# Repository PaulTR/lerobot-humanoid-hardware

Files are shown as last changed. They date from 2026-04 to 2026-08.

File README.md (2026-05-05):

# lerobot-humanoid-hardware

Hardware repository for **LeRobot Humanoid**.

This repo stores the practical build assets needed to reproduce the robot hardware:
- mechanical assembly documentation
- manufacturing files and notes
- electronics wiring and connector mapping
- bill of materials (BOM)
- motor pre-assembly commissioning tooling

## Current scope

- `IN`: biped platform hardware
- `OUT` (for now): upper-body hardware

The Onshape document currently contains an upper-body model as well, but this repository iteration tracks only the biped platform assets.

## CAD source of truth

Primary CAD source (Onshape):
- **Public Onshape CAD (open this first):** https://cad.onshape.com/documents/fb645318a27646d1d8840be6/w/d1cae8805fb652b4d1614997/e/804a1da43f242001a05129b4

Referenced IDs:
- Document ID: `fb645318a27646d1d8840be6`
- Workspace ID: `d1cae8805fb652b4d1614997`
- Element ID: `804a1da43f242001a05129b4`

## Repository layout

- `docs/`: architecture, guides, and procedures
- `hardware/cad/`: Onshape source reference and exported STL geometry
- `hardware/bom/`: BOM in machine-readable and human-readable formats
- `hardware/config/`: motor commissioning utilities
- `hardware/electronics/`: wiring and connector mapping

## CAD organization

`hardware/cad/stl/` is split by side and subassembly:
- `biped_platform/left_leg/{hipx,hipz,thigh,knee_mechanism,shin,ankle_mechanism,ankle,foot}`
- `biped_platform/right_leg/{hipx,hipz,thigh,knee_mechanism,shin,ankle_mechanism,ankle,foot}`
- `biped_platform/torso`

This mirrors the assembly view and makes part export placement explicit.

## Runtime integration

Runtime repository (robot model and control runtime) lives in:
- https://github.com/Virgileboat/lerobot-humanoid-runtime

Motor commissioning script in this repo is self-contained and does **not** depend on `robstride_toolkit`.

Main scripts:
- `hardware/config/commission_motor.py`

## Start Sequence (Human + Agent)

Use this preferred order to start a new build:

1. Order all buy parts from `hardware/bom/bom_buy.csv` first.
2. Print all required STL parts from `docs/manufacturing/printing_guide.md`.
3. Commission and check every motor before assembly:
   - `docs/electronics/motor_commissioning.md`
   - `python hardware/config/commission_motor.py wizard --channel can0`
4. Assemble mechanical subassemblies using `docs/assembly/assembly_guide.md`.
5. Run wiring and first power-on checks:
   - `docs/electronics/check_wiring.md`
   - `docs/electronics/first_power_on.md`

Important rule:
- Do not start mechanical assembly before motor protocol/ID commissioning and motion check are completed.

## Support

If you are blocked on build, printing, electronics, or assembly details:
- contact: `virgilebatto@gmail.com`

## Working model

1. Modify design in Onshape.
2. Export manufacturing/build assets to this repository.
3. Update BOM/config/docs in the same commit.
4. Keep all biped-platform changes traceable to a CAD revision.

## BOM Split (Robot Qty)

### STL BOM

| Subassembly | STL files to print |
|---|---:|
| torso | 7 |
| hipx | 2 |
| hipz | 4 |
| thigh | 6 |
| knee_mechanism | 6 |
| shin | 12 |
| ankle_mechanism | 16 |
| ankle | 10 |
| foot | 12 |
| **Total** | **75** |

Detailed STL names and quantities:
- [Printing guide](docs/manufacturing/printing_guide.md)
- [BOM total (clickable STL rows)](hardware/bom/bom.md)
- [BOM CSV (`category=stl_print`)](hardware/bom/bom.csv)

### Bearing/Revolute BOM

| Name | Specification | Qty (robot) |
|---|---|---:|
| Bearing | 35x72x17 | 4 |
| Bearing | 15x21x4 | 14 |
| Bearing | 5x16x5 | 8 |
| Spherical joint 27628-01-05 | Norelem | 8 |

### Axis BOM

| Name | Specification | Qty (robot) | Usage |
|---|---|---:|---|
| Shoulder screw 07534-05X40 | ISO7379, D1=5, L1=40, B=8, M4, SW=2.5, steel 12.9 | 4 | thigh (2) + ankle (2) |
| Shoulder screw 07534-05X20 | ISO7379, D1=5, L1=20, B=8, M4, steel 12.9 | 8 | ankle_mechanism (8) |

### Screw BOM

| Name | Specification | Qty (robot) |
|---|---|---:|
| M2 screw | M2 x 5 cyl head | 4 |
| M2.5 screw | M2.5 x 20 cyl head | 9 |
| M2.5 screw | M2.5 x 6 cyl head | 6 |
| M2.5 screw | M2.5 x 8 cyl head | 24 |
| M3 screw | M3 x 8 cyl head | 18 |
| M3 screw | M3 x 10 cyl head | 48 |
| M3 screw | M3 x 12.5 cyl head | 6 |
| M3 screw | M3 x 17.5 cyl head | 8 |
| M4 screw | M4 x 8 cyl head | 36 |
| M4 screw | M4 x 10 cyl head | 42 |
| M4 screw | M4 x 16 cyl head | 16 |
| M4 screw | M4 x 18 cyl head | 32 |
| M4 screw | M4 x 20 cyl head | 32 |
| M4 screw | M4 x 23.5 cyl head | 8 |
| M4 screw | M4 x 40 cyl head | 12 |
| M4 screw | M4 x 45 cyl head | 18 |
| M5 screw | M5 x 10 cyl head | 5 |
| M5 screw | M5 x 15 cyl head | 8 |

## Cost estimate (Biped Platform, April 30 2026)

Scope of this estimate:
- all buy items in `hardware/bom/bom_buy.csv`
- plus PLA+ filament for printing (`~3.5 kg` used for estimate, target range `3-4 kg`)

Assumptions:
- currency: `USD`
- prices are indicative and vendor-dependent
- excludes shipping, import duties, and local taxes
- fastener prices use bulk-piece estimates
- EUR-priced references converted with `1 EUR = 1.1691 USD` (snapshot on `May 5, 2026`)
- `hipx` M3 screw line is optional and can be removed without issue

| Subassembly | Category | Name | Specification | Qty (robot) | Unit est. (USD) | Subtotal est. (USD) |
|---|---|---|---|---:|---:|---:|
| torso | electronics_controller | Raspberry Pi 5 | single-board computer | 1 | 130.00 | 130.00 |
| torso | electronics_imu | IMU | BNO055 or BNO085 | 1 | 64.00 | 64.00 |
| torso | electronics_canfd_adapter | SAVVYCANFD 2CH CANFD adapter | USB, dual CAN FD, 12 Mbps max | 1 | 59.00 | 59.00 |
| torso | cable_power | Power cable red | diameter >= 2.5 mm, 5 m | 1 | 15.00 | 15.00 |
| torso | cable_power | Power cable black | diameter >= 2.5 mm, 5 m | 1 | 15.00 | 15.00 |
| torso | cable_communication | Communication cable color 1 | 5 m | 1 | 8.00 | 8.00 |
| torso | cable_communication | Communication cable color 2 | 5 m | 1 | 8.00 | 8.00 |
| torso | motor | RobStride O0 | actuator | 2 | 125.00 | 250.00 |
| torso | fastener_screw | M2 screw | M2 x 5 cyl head | 4 | 0.10 | 0.40 |
| torso | fastener_screw | M2.5 screw | M2.5 x 20 cyl head | 9 | 0.12 | 1.08 |
| torso | fastener_screw | M3 screw | M3 x 8 cyl head | 12 | 0.10 | 1.20 |
| torso | fastener_screw | M4 screw | M4 x 20 cyl head | 16 | 0.14 | 2.24 |
| torso | fastener_screw | M5 screw | M5 x 10 cyl head | 5 | 0.20 | 1.00 |
| hipx | fastener_screw | M3 screw | M3 x 8 cyl head | 6 | 0.10 | 0.60 |
| hipx | fastener_screw | M4 screw | M4 x 40 cyl head | 12 | 0.17 | 2.04 |
| hipx | fastener_screw | M4 screw | M4 x 45 cyl head | 18 | 0.20 | 3.60 |
| hipx | fastener_screw | M4 screw | M4 x 8 cyl head | 16 | 0.10 | 1.60 |
| hipz | motor | RobStride O2 | actuator | 2 | 145.00 | 290.00 |
| hipz | bearing | Bearing | 35x72x17 | 4 | 8.27 | 33.08 |
| hipz | fastener_screw | M4 screw | M4 x 10 cyl head | 16 | 0.11 | 1.76 |
| hipz | fastener_screw | M4 screw | M4 x 20 cyl head | 16 | 0.14 | 2.24 |
| thigh | motor | RobStride O3 | actuator | 4 | 225.00 | 900.00 |
| thigh | bearing | Bearing | 15x21x4 | 2 | 3.00 | 6.00 |
| thigh | bearing | Bearing | 5x16x5 | 4 | 1.87 | 7.48 |
| thigh | fastener_screw | M2.5 screw | M2.5 x 6 cyl head | 6 | 0.09 | 0.54 |
| thigh | fastener_screw | M4 screw | M4 x 10 cyl head | 8 | 0.11 | 0.88 |
| thigh | fastener_screw | M4 screw | M4 x 23.5 cyl head | 8 | 0.16 | 1.28 |
| thigh | fastener_screw | M4 screw | M4 x 8 cyl head | 20 | 0.10 | 2.00 |
| thigh | fastener_axis | Shoulder screw 07534-05X40 | ISO7379, D1=5, L1=40, B=8, M4, SW=2.5, steel 12.9 | 2 | 8.18 | 16.36 |
| knee_mechanism | bearing | Bearing | 15x21x4 | 4 | 3.00 | 12.00 |
| knee_mechanism | fastener_screw | M3 screw | M3 x 12.5 cyl head | 6 | 0.11 | 0.66 |
| knee_mechanism | fastener_screw | M4 screw | M4 x 16 cyl head | 16 | 0.12 | 1.92 |
| shin | motor | RobStride O5 | actuator | 4 | 110.00 | 440.00 |
| shin | bearing | Bearing | 15x21x4 | 8 | 3.00 | 24.00 |
| shin | fastener_screw | M2.5 screw | M2.5 x 8 cyl head | 6 | 0.10 | 0.60 |
| shin | fastener_screw | M3 screw | M3 x 17.5 cyl head | 8 | 0.12 | 0.96 |
| shin | fastener_screw | M3 screw | M3 x 10 cyl head | 48 | 0.10 | 4.80 |
| shin | fastener_screw | M4 screw | M4 x 18 cyl head | 32 | 0.14 | 4.48 |
| shin | fastener_screw | M4 screw | M4 x 10 cyl head | 18 | 0.11 | 1.98 |
| shin | fastener_nut | Nut M4 | M4 nut | 6 | 0.08 | 0.48 |
| shin | fastener_insert | Heat-set insert M3 | brass threaded insert M3 | 8 | 0.10 | 0.80 |
| ankle_mechanism | fastener_screw | M5 screw | M5 x 15 cyl head | 8 | 0.24 | 1.92 |
| ankle_mechanism | joint_spherical | Spherical joint 27628-01-05 | Norelem | 8 | 20.93 | 167.44 |
| ankle_mechanism | fastener_axis | Shoulder screw 07534-05X20 | ISO7379, D1=5, L1=20, B=8, M4, steel 12.9 | 8 | 6.35 | 50.80 |
| ankle | fastener_screw | M2.5 screw | M2.5 x 8 cyl head | 12 | 0.10 | 1.20 |
| ankle | fastener_axis | Shoulder screw 07534-05X40 | ISO7379, D1=5, L1=40, B=8, M4, SW=2.5, steel 12.9 | 2 | 8.18 | 16.36 |
| foot | bearing | Bearing | 5x16x5 | 4 | 1.87 | 7.48 |
| foot | fastener_screw | M2.5 screw | M2.5 x 8 cyl head | 6 | 0.10 | 0.60 |
| foot | fastener_nut | Nut M4 | M4 nut | 6 | 0.08 | 0.48 |
| assembly_pins | fastener_pin | Pin d3mm | d3 pin (goupille) | 8 | 0.45 | 3.60 |
| assembly_pins | fastener_pin | Pin d4mm | d4 pin (goupille) | 18 | 0.55 | 9.90 |
| tools | tool | Allen key | 2.5 mm | 1 | 3.00 | 3.00 |
| manufacturing | consumable_filament | PLA+ filament | ~3.5 kg total (target range 3-4 kg) | 1 | 56.00 | 56.00 |

| Cost block | Estimate (USD) |
|---|---:|
| ankle subtotal | 17.56 |
| ankle_mechanism subtotal | 220.16 |
| assembly_pins subtotal | 13.50 |
| foot subtotal | 8.56 |
| hipx subtotal | 7.84 |
| hipz subtotal | 327.08 |
| knee_mechanism subtotal | 14.58 |
| shin subtotal | 478.10 |
| thigh subtotal | 934.54 |
| tools subtotal | 3.00 |
| torso subtotal | 554.92 |
| BOM-to-buy subtotal (without filament) | 2579.84 |
| PLA+ subtotal (~3.5 kg) | 56.00 |
| **Estimated total** | **2635.84** |

Price anchors used for key components:
- RobStride official site (motors): https://www.robstride.com/
- RobStride official product information: https://github.com/RobStride/Product_Information
- Raspberry Pi 5 (8GB): https://www.sparkfun.com/products/23551
- IMU BNO085: https://www.ardusimple.com/product/adafruit-9-dof-orientation-imu-fusion-breakout-bno085/
- SAVVYCANFD adapter: https://www.pibiger-tech.com/product/savvycan-fd-c/
- Bearing 5x16x5 reference price (123roulement): https://www.123roulement.com/roulement-palier/roulement-bille/simple-rangee/625-zz
- Bearing 35x72x17 reference price (123roulement): https://www.123roulement.com/roulement-palier/roulement-bille/simple-rangee/6207
- Norelem shoulder screw series 07534 (axis refs 07534-05X20 / 07534-05X40): https://www.norelem.fr/fr/Aper%C3%A7u%2Bdu%2Bproduit/Syst%C3%A8me-flexible-de-pi%C3%A8ces-standardis%C3%A9es/07000/%C3%89crous-vis-rondelles-%C3%A9l%C3%A9ments-de-fi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
- Norelem rod end series 27628 (spherical joint ref 27628-01-05): https://www.norelem.fr/en/Product-overview/Systems-and-components-for-machine-and-plant-construction/27000/Rod-ends/Rod-ends-with-plain-bearing-internal-thread-DIN-I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
- PLA+ reference price: https://us.elegoo.com/products/elegoo-rapid-pla-plus-filament-1-75mm-colored-1kg

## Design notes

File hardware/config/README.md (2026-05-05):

# Config

This folder is for pre-assembly motor commissioning only.

Tool:
- `commission_motor.py`

Typical use:

```bash
python hardware/config/commission_motor.py scan --channel can0
python hardware/config/commission_motor.py wizard --channel can0
python hardware/config/commission_motor.py wizard --channel can0 --motor-model o3 --new-id 4 --yes
```

Scope boundary:
- robot model and runtime control are maintained in https://github.com/Virgileboat/lerobot-humanoid-runtime

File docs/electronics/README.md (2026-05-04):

# Electronics

Electronics documentation for the biped platform.

Core artifacts:
- full wiring diagram image (`hardware/electronics/wiring_diagram.png`)
- connector and pin mapping (`hardware/electronics/connectors.md`)
- connector photo catalog (`hardware/electronics/connectors_photos/`)
- leg sub-cable diagrams with embedded images (`hardware/electronics/cabling/README.md`)
- power distribution notes
- controller and actuator bus topology

Leg sub-cable set (same cabling for left and right leg):
- legend, shin, thigh, and hip pass-through diagrams are embedded in `hardware/electronics/cabling/README.md`.

Motor pre-assembly commissioning:
- detailed workflow: `docs/electronics/motor_commissioning.md`
- tool: `hardware/config/commission_motor.py`
- recommended entrypoint: `wizard` command
- covers protocol detection, MIT switch, model-based ID assignment, and motion check

Implementation note:
- this script embeds only the CAN functions it uses; it does not import `robstride_toolkit`.

Bring-up runbooks:
- `docs/electronics/check_wiring.md`
- `docs/electronics/first_power_on.md`

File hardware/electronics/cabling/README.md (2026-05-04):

# Leg Cabling Diagrams

This folder contains the leg sub-cable diagrams used on the robot.

The same cabling architecture is used for both left and right legs.
The split by `shin` / `thigh` / `hip` is intentional to simplify debugging and repair.

## Legend

`red = power`, `green = CAN`, `blue = CAN + power`

Cable legend

## Shin sub-cable

Shin sub-cable

## Thigh sub-cable

Thigh sub-cable

## Hip pass-through sub-cable

Hip pass-through sub-cable

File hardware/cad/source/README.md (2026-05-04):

# CAD Source

Canonical CAD is maintained in Onshape:
- https://cad.onshape.com/documents/fb645318a27646d1d8840be6/w/d1cae8805fb652b4d1614997/e/804a1da43f242001a05129b4

Reference IDs:
- document: `fb645318a27646d1d8840be6`
- workspace: `d1cae8805fb652b4d1614997`
- default element: `804a1da43f242001a05129b4`

Current repo scope:
- biped platform only

CAD organization for this repo:
- `biped_platform/left_leg/`
- `biped_platform/right_leg/`
- `biped_platform/torso/`

Export policy:
1. Keep Onshape as source of truth.
2. Export `STL` for manufacturing where needed.
3. Include date/revision in exported filenames.
4. Update BOM and docs in the same commit.

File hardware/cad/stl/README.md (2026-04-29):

# STL Exports

Store manufacturing meshes (`.stl`) here.

Split exports by assembly hierarchy:
- `biped_platform/left_leg/<group>/...`
- `biped_platform/right_leg/<group>/...`
- `biped_platform/torso/...`

Current leg groups:
- `ankle`
- `ankle_mechanism`
- `foot`
- `hipx`
- `hipz`
- `knee_mechanism`
- `shin`
- `thigh`

Filename convention:
- ASCII lowercase snake_case.
- No spaces.
- No parentheses, so no `(1)`, `(2)`, etc.
- Repeated physical instances keep explicit numeric indices in the name (example: `...14...`, `...24...`, `...34...`, `...44...`).

Example:
`right_leg/shin/tibias2_tibias22.stl`

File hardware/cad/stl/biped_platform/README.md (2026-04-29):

# Biped Platform STL

Store STL exports split by side and mechanical group.

Main structure:
- `left_leg/<group>/...`
- `right_leg/<group>/...`
- `torso/...`

Per-leg groups currently used:
- `ankle`
- `ankle_mechanism`
- `foot`
- `hipx`
- `hipz`
- `knee_mechanism`
- `shin`
- `thigh`

Filename rule:
- Use lowercase snake_case.
- Do not use parentheses in filenames.
- Keep explicit instance indices when the same part appears multiple times.

Example path:
`right_leg/ankle_mechanism/bearing_spacer14_5_7_3.stl`

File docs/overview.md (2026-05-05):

# Overview

This repository is the build reference for **LeRobot Humanoid hardware**.

## Scope boundary

Current tracked hardware scope:
- biped platform (legs + base-related hardware)

Not yet tracked in this repo iteration:
- upper-body hardware present in the current Onshape document

## Source systems

- CAD source of truth: Onshape document (`fb645318a27646d1d8840be6`)
- Build source of truth: this repository
- Runtime control/model source: https://github.com/Virgileboat/lerobot-humanoid-runtime

## CAD split

CAD source is maintained in Onshape.  
This repository stores STL exports under:
- `hardware/cad/stl/biped_platform/left_leg/*`
- `hardware/cad/stl/biped_platform/right_leg/*`
- `hardware/cad/stl/biped_platform/torso/*`

## Traceability rules

For every hardware change:
1. Link it to a CAD revision/context in commit message or PR notes.
2. Update BOM (`hardware/bom/bom.csv`) if parts change.
3. If geometry/kinematics change, update runtime model/control artifacts in https://github.com/Virgileboat/lerobot-humanoid-runtime.
4. Update assembly/manufacturing docs if process changes.

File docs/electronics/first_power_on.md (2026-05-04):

# First Power-On Procedure

## Phase 1: logic power only

1. Power controller logic rails only.
2. Set bench supply current limit to `2 A` for this first test phase (no motion capability expected).
3. Confirm expected idle current is around `1 A` maximum.
4. If current rises above `2 A`, stop immediately and re-check wiring before continuing.
5. Confirm communication with all controller nodes.
6. Verify watchdog/heartbeat behavior.

## Phase 2: actuator power with safety limits

1. Set low current/torque limits.
2. Enable one actuator at a time.
3. Verify sign/direction and encoder consistency.
4. Disable immediately if unexpected motion occurs.

## Phase 3: low-amplitude validation

1. Execute tiny motion commands around neutral position.
2. Confirm software limits are enforced.
3. Log observed offsets and runtime notes for later integration in `lerobot_humanoid_runtime`.

Stop criteria:
- unexpected heating, smell, noise, or oscillation
- communication instability under load
- any limit/safety mismatch

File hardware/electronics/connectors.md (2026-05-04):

# Connectors

## Visual connector catalog (used on this robot)

### Inter-cable connector (male)

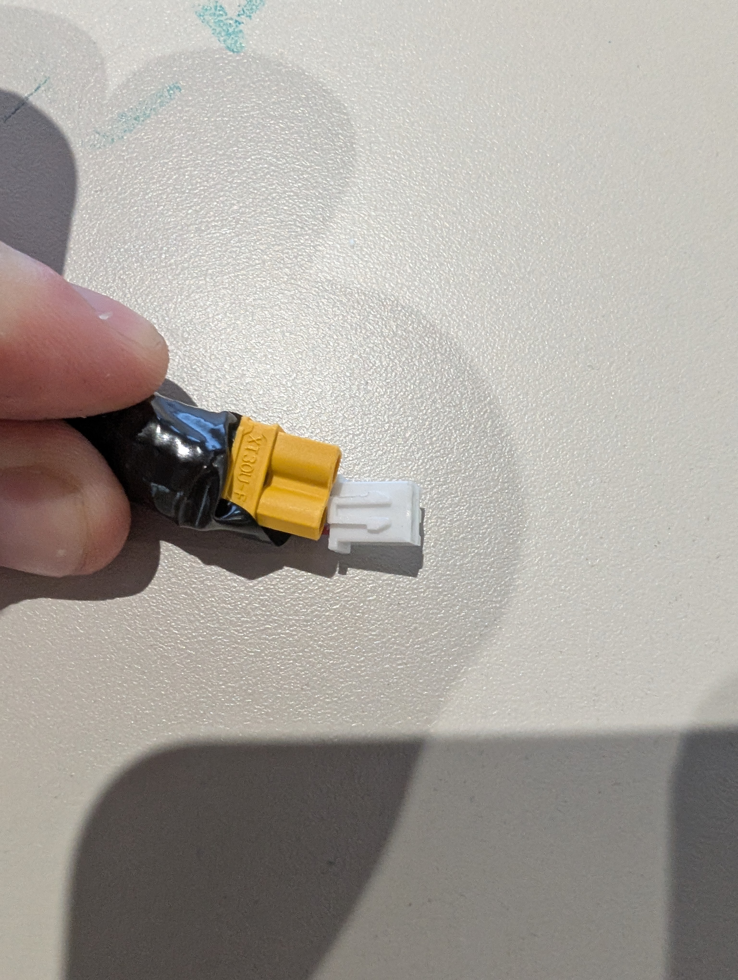
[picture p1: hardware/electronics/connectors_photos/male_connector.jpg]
Inter-cable male connector


### Inter-cable connector (female)

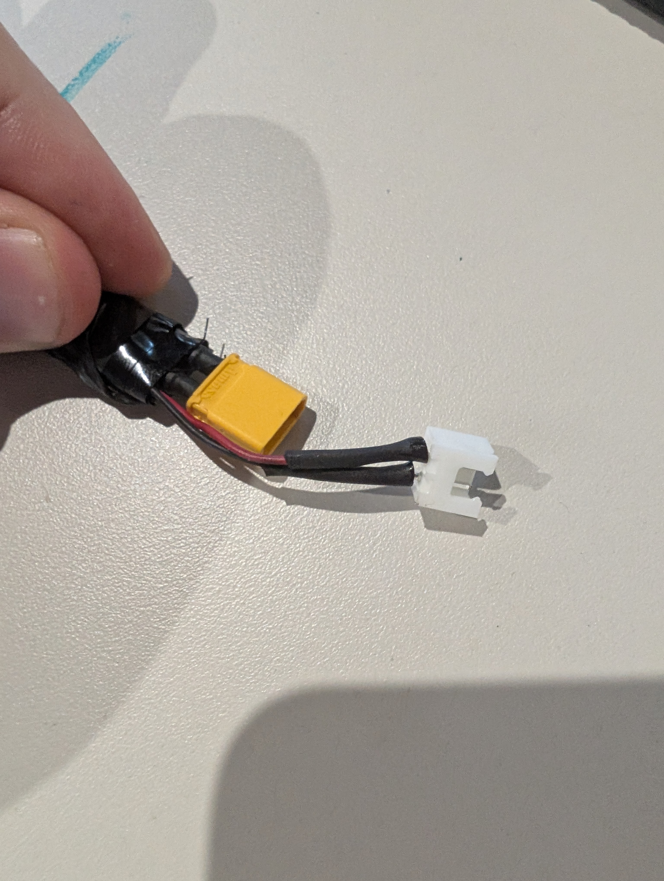
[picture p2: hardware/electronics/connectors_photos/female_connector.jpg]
Inter-cable female connector


### RobStride O3-side connector

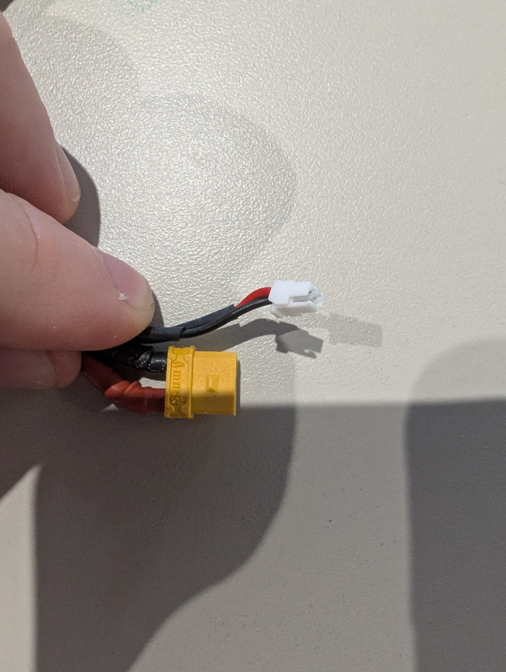
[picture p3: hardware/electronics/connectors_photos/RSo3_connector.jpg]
RobStride O3 connector


### RobStride connector (other RobStride models used here)

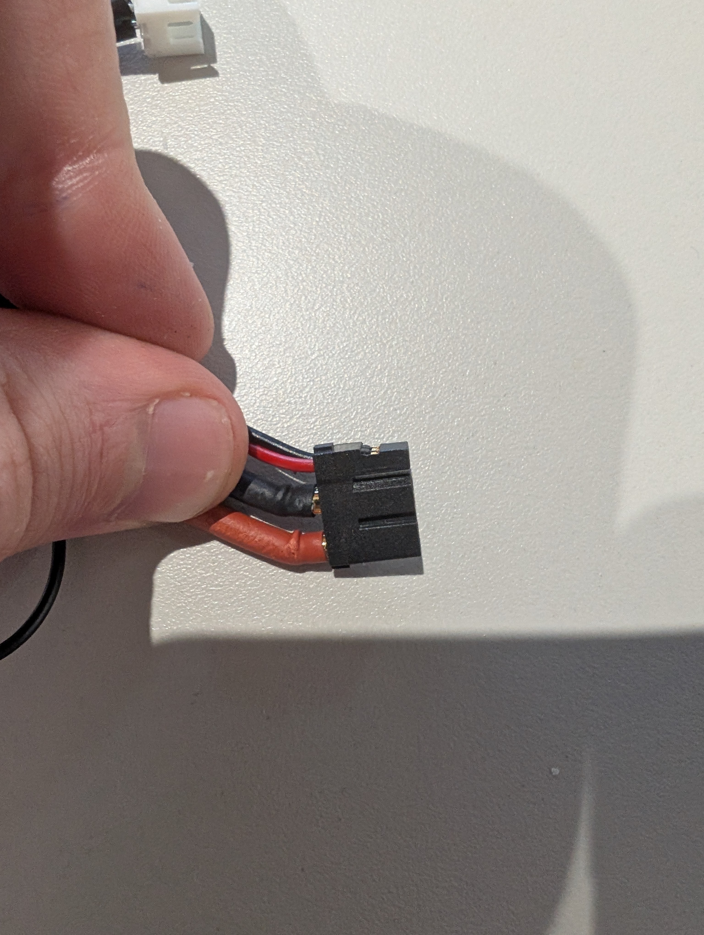
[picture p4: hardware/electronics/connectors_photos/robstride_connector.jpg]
RobStride connector (non-O3)


### XT30 power connector

XT30 is used to connect to the power source.  
XT30 is visible on the connector photos above (yellow power connector body).

## Connector map (biped platform)

| Connector ID | Function | Board Side | Device Side | Pinout Status | Notes |
|---|---|---|---|---|---|
| CONN-CANFD-ADAPTER-01 | USB to dual CAN-FD interface | USB-A host | USB-A plug | defined | SAVVYCANFD 2CH CANFD adapter |
| CONN-CANFD-CH0-DB9 | CAN channel 0 (torso/left bus split as needed) | DB9 female on adapter (`CAN0`) | DB9 harness | partial | Known pins: `2=CAN-L`, `3=GND`, `7=CAN-H` |
| CONN-CANFD-CH1-DB9 | CAN channel 1 (torso/right bus split as needed) | DB9 female on adapter (`CAN1`) | DB9 harness | partial | Known pins: `2=CAN-L`, `3=GND`, `7=CAN-H` |
| CONN-PWR-01 | Main power in | XT30 pair | XT30 pair | partial | Main robot power entry |
| CONN-LEG-LINK-01 | Leg sub-cable interconnect | male inter-cable connector | female inter-cable connector | partial | Used between shin/thigh/hip cable subgroups |
| CONN-MOTOR-O3-01 | Motor-side connector for RobStride O3 | harness side `RSo3_connector` | motor side | partial | Use the O3-specific connector shown above |
| CONN-MOTOR-RS-OTHER-01 | Motor-side connector for other RobStride models used here | harness side `robstride_connector` | motor side | partial | Use the non-O3 RobStride connector shown above |

## To complete

- Commercial references used here:
  - XT30 for main power connection.
  - XH-2A / XH-2Y for inter-cable connection.
- Pin-level documentation policy for motor harnesses:
  - keep only the required signals in docs: `PWR+`, `PWR-`, `CAN-H`, `CAN-L`.
- Power wiring target:
  - size power lines for up to `30 A` per cable branch.
- CAN termination:
  - keep standard `120 ohm` termination at both bus ends.
  - bus-end termination is currently handled by the USB-CAN adapter side in this setup.

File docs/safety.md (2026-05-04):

# Safety

## Minimum safety requirements

- Keep a physical emergency power cutoff accessible.
- Use current-limited bench supply for first electronics checks.
- Verify motor direction and limits at low torque/current first.
- Keep clear of moving joints during bring-up.
- Never run unattended during first powered motion passes.

## Power bring-up rules

1. Validate wiring continuity before connecting battery/high-current source.
2. Bring up logic power before actuator power.
3. Confirm communication heartbeat and watchdog behavior.
4. Enable actuators only after limit/zero checks pass.

## Mechanical checks before motion

- Fastener torque check completed.
- Structural parts inspected for cracks/print defects.
- Joint free motion verified by hand (power off).
- Cable strain relief and routing confirmed.

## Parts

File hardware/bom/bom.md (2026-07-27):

# BOM Total

## motors

| name | subassembly | qty_subassembly | qty_robot |
|---|---|---:|---:|
| RobStride O0 | torso | 2 | 2 |
| RobStride O2 | hipz | 1 | 2 |
| RobStride O3 | thigh | 2 | 4 |
| RobStride O5 | shin | 2 | 4 |

## torso

| category | name | specification | qty_subassembly | qty_robot |
|---|---|---|---:|---:|
| electronics_controller | Raspberry Pi 5 | single-board computer | 1 | 1 |
| electronics_imu | IMU | BNO055 or BNO085 | 1 | 1 |
| electronics_canfd_adapter | SAVVYCANFD 2CH CANFD adapter | USB, dual CAN FD, 12 Mbps max | 1 | 1 |
| cable_power | Power cable red | diameter >= 2.5 mm, 5 m | 1 | 1 |
| cable_power | Power cable black | diameter >= 2.5 mm, 5 m | 1 | 1 |
| cable_communication | Communication cable color 1 | 5 m | 1 | 1 |
| cable_communication | Communication cable color 2 | 5 m | 1 | 1 |
| motor | RobStride O0 | actuator | 2 | 2 |
| fastener_screw | M2 screw | M2 x 5 cyl head | 4 | 4 |
| fastener_screw | M2.5 screw | M2.5 x 20 cyl head | 9 | 9 |
| fastener_screw | M3 screw | M3 x 8 cyl head | 12 | 12 |
| fastener_screw | M4 screw | M4 x 20 cyl head | 16 | 16 |
| fastener_screw | M5 screw | M5 x 10 cyl head | 5 | 5 |

> Comment: cheaper or better CAN-FD adapters may exist, but this one is currently the only adapter proven in this project to handle the RobStride CAN protocol.

### stl_to_print
| name | quantity |
|---|---:|
| [torso_can_holder.stl](../cad/stl/biped_platform/torso/torso_can_holder.stl) | 1 |
| [torso_can_holder.stl](../cad/stl/biped_platform/torso/torso_can_holder_2.stl) | 1 |
| [torso_imu_holder.stl](../cad/stl/biped_platform/torso/torso_imu_holder.stl) | 1 |
| [torso_torso13.stl](../cad/stl/biped_platform/torso/torso_torso13.stl) | 1 |
| [torso_torso23.stl](../cad/stl/biped_platform/torso/torso_torso23.stl) | 1 |
| [torso_torso33.stl](../cad/stl/biped_platform/torso/torso_torso33.stl) | 1 |
| [torso_uper_torso_22.stl](../cad/stl/biped_platform/torso/torso_uper_torso_22.stl) | 1 |
| [torso_upper_torso_12.stl](../cad/stl/biped_platform/torso/torso_upper_torso_12.stl) | 1 |

## hipx

| category | name | specification | qty_subassembly | qty_robot |
|---|---|---|---:|---:|
| fastener_screw | M3 screw | M3 x 8 cyl head | 3 | 6 |
| fastener_screw | M4 screw | M4 x 40 cyl head | 6 | 12 |
| fastener_screw | M4 screw | M4 x 45 cyl head | 9 | 18 |
| fastener_screw | M4 screw | M4 x 8 cyl head | 8 | 16 |

> Comment: the `hipx` M3 screw line is optional and can be removed without issue.

### stl_to_print_left_leg
| name | quantity |
|---|---:|
| [hipx_2_hipxy_sym.stl](../cad/stl/biped_platform/left_leg/hipx/hipx_2_hipxy_sym.stl) | 1 |

### stl_to_print_right_leg
| name | quantity |
|---|---:|
| [hipx_2_hipxy.stl](../cad/stl/biped_platform/right_leg/hipx/hipx_2_hipxy.stl) | 1 |

## hipz

| category | name | specification | qty_subassembly | qty_robot |
|---|---|---|---:|---:|
| motor | RobStride O2 | actuator | 1 | 2 |
| bearing | Bearing | 35x72x17 | 2 | 4 |
| fastener_screw | M4 screw | M4 x 10 cyl head | 8 | 16 |
| fastener_screw | M4 screw | M4 x 20 cyl head | 8 | 16 |

### stl_to_print_left_leg
| name | quantity |
|---|---:|
| [hip_z_hipz12_sym.stl](../cad/stl/biped_platform/left_leg/hipz/hip_z_hipz12_sym.stl) | 1 |
| [hip_z_hipz22_sym.stl](../cad/stl/biped_platform/left_leg/hipz/hip_z_hipz22_sym.stl) | 1 |

### stl_to_print_right_leg
| name | quantity |
|---|---:|
| [hip_z_hipz12.stl](../cad/stl/biped_platform/right_leg/hipz/hip_z_hipz12.stl) | 1 |
| [hip_z_hipz22.stl](../cad/stl/biped_platform/right_leg/hipz/hip_z_hipz22.stl) | 1 |

## thigh

| category | name | specification | qty_subassembly | qty_robot |
|---|---|---|---:|---:|
| motor | RobStride O3 | actuator | 2 | 4 |
| bearing | Bearing | 15x21x4 | 1 | 2 |
| bearing | Bearing | 5x16x5 | 2 | 4 |
| fastener_screw | M2.5 screw | M2.5 x 6 cyl head | 3 | 6 |
| fastener_screw | M4 screw | M4 x 10 cyl head | 4 | 8 |
| fastener_screw | M4 screw | M4 x 23.5 cyl head | 4 | 8 |
| fastener_screw | M4 screw | M4 x 8 cyl head | 10 | 20 |
| fastener_axis | Shoulder screw 07534-05X40 | ISO7379, D1=5, L1=40, B=8, M4, SW=2.5, steel 12.9 | 1 | 2 |

### stl_to_print_left_leg
| name | quantity |
|---|---:|
| [femur_v2_femur_12_sym_1.stl](../cad/stl/biped_platform/left_leg/thigh/femur_v2_femur_12_sym_1.stl) | 1 |
| [femur_v2_femur_22_sym_1.stl](../cad/stl/biped_platform/left_leg/thigh/femur_v2_femur_22_sym_1.stl) | 1 |
| [femur_v2_hat_femur_2.stl](../cad/stl/biped_platform/left_leg/thigh/femur_v2_hat_femur_2.stl) | 1 |

### stl_to_print_right_leg
| name | quantity |
|---|---:|
| [femur_v2_femur_12_1.stl](../cad/stl/biped_platform/right_leg/thigh/femur_v2_femur_12_1.stl) | 1 |
| [femur_v2_femur_22_1.stl](../cad/stl/biped_platform/right_leg/thigh/femur_v2_femur_22_1.stl) | 1 |
| [femur_v2_hat_femur_2.stl](../cad/stl/biped_platform/right_leg/thigh/femur_v2_hat_femur_2.stl) | 1 |

## knee_mechanism

| category | name | specification | qty_subassembly | qty_robot |
|---|---|---|---:|---:|
| bearing | Bearing | 15x21x4 | 2 | 4 |
| fastener_screw | M3 screw | M3 x 12.5 cyl head | 3 | 6 |
| fastener_screw | M4 screw | M4 x 16 cyl head | 8 | 16 |

### stl_to_print_left_leg
| name | quantity |
|---|---:|
| [femur_v2_knee_actuation_2.stl](../cad/stl/biped_platform/left_leg/knee_mechanism/femur_v2_knee_actuation_2.stl) | 1 |
| [femur_v2_knee_rod12_sym_1.stl](../cad/stl/biped_platform/left_leg/knee_mechanism/femur_v2_knee_rod12_sym_1.stl) | 1 |
| [femur_v2_knee_rod22_sym_1.stl](../cad/stl/biped_platform/left_leg/knee_mechanism/femur_v2_knee_rod22_sym_1.stl) | 1 |

### stl_to_print_right_leg
| name | quantity |
|---|---:|
| [femur_v2_knee_actuation_1.stl](../cad/stl/biped_platform/right_leg/knee_mechanism/femur_v2_knee_actuation_1.stl) | 1 |
| [femur_v2_knee_rod12_1.stl](../cad/stl/biped_platform/right_leg/knee_mechanism/femur_v2_knee_rod12_1.stl) | 1 |
| [femur_v2_knee_rod22_1.stl](../cad/stl/biped_platform/right_leg/knee_mechanism/femur_v2_knee_rod22_1.stl) | 1 |

## shin

| category | name | specification | qty_subassembly | qty_robot |
|---|---|---|---:|---:|
| motor | RobStride O5 | actuator | 2 | 4 |
| bearing | Bearing | 15x21x4 | 4 | 8 |
| fastener_screw | M2.5 screw | M2.5 x 8 cyl head | 3 | 6 |
| fastener_screw | M3 screw | M3 x 17.5 cyl head | 4 | 8 |
| fastener_screw | M3 screw | M3 x 10 cyl head | 24 | 48 |
| fastener_screw | M4 screw | M4 x 18 cyl head | 16 | 32 |
| fastener_screw | M4 screw | M4 x 10 cyl head | 9 | 18 |
| fastener_nut | Nut M4 | M4 nut | 3 | 6 |
| fastener_insert | Heat-set insert M3 | brass threaded insert M3 | 4 | 8 |

### stl_to_print_left_leg
| name | quantity |
|---|---:|
| [spacer12_5_9_4_5.stl](../cad/stl/biped_platform/left_leg/shin/spacer12_5_9_4_5.stl) | 1 |
| [spacer22_5_9_4_5.stl](../cad/stl/biped_platform/left_leg/shin/spacer22_5_9_4_5.stl) | 1 |
| [tibias2_hat_big.stl](../cad/stl/biped_platform/left_leg/shin/tibias2_hat_big.stl) | 1 |
| [tibias2_shin_spacer_2.stl](../cad/stl/biped_platform/left_leg/shin/tibias2_shin_spacer_2.stl) | 1 |
| [tibias2_tibias12_sym_4.stl](../cad/stl/biped_platform/left_leg/shin/tibias2_tibias12_sym_4.stl) | 1 |
| [tibias2_tibias22_sym_4.stl](../cad/stl/biped_platform/left_leg/shin/tibias2_tibias22_sym_4.stl) | 1 |

### stl_to_print_right_leg
| name | quantity |
|---|---:|
| [spacer12_5_9_4_5.stl](../cad/stl/biped_platform/right_leg/shin/spacer12_5_9_4_5.stl) | 1 |
| [spacer22_5_9_4_5.stl](../cad/stl/biped_platform/right_leg/shin/spacer22_5_9_4_5.stl) | 1 |
| [tibias2_hat_big.stl](../cad/stl/biped_platform/right_leg/shin/tibias2_hat_big.stl) | 1 |
| [tibias2_shin_spacer_2.stl](../cad/stl/biped_platform/right_leg/shin/tibias2_shin_spacer_2.stl) | 1 |
| [tibias2_tibias12.stl](../cad/stl/biped_platform/right_leg/shin/tibias2_tibias12.stl) | 1 |
| [tibias2_tibias22.stl](../cad/stl/biped_platform/right_leg/shin/tibias2_tibias22.stl) | 1 |

## ankle_mechanism

| category | name | specification | qty_subassembly | qty_robot |
|---|---|---|---:|---:|
| fastener_screw | M5 screw | M5 x 15 cyl head | 4 | 8 |
| joint_spherical | Spherical joint 27628-01-05 | Norelem | 4 | 8 |
| fastener_axis | Shoulder screw 07534-05X20 | ISO7379, D1=5, L1=20, B=8, M4, steel 12.9 | 4 | 8 |

### stl_to_print_left_leg
| name | quantity |
|---|---:|
| [bearing_spacer14_5_7_3.stl](../cad/stl/biped_platform/left_leg/ankle_mechanism/bearing_spacer14_5_7_3.stl) | 1 |
| [bearing_spacer24_5_7_3.stl](../cad/stl/biped_platform/left_leg/ankle_mechanism/bearing_spacer24_5_7_3.stl) | 1 |
| [bearing_spacer34_5_7_3.stl](../cad/stl/biped_platform/left_leg/ankle_mechanism/bearing_spacer34_5_7_3.stl) | 1 |
| [bearing_spacer44_5_7_3.stl](../cad/stl/biped_platform/left_leg/ankle_mechanism/bearing_spacer44_5_7_3.stl) | 1 |
| [tibias2_rod_long.stl](../cad/stl/biped_platform/left_leg/ankle_mechanism/tibias2_rod_long.stl) | 1 |
| [tibias2_rod_small.stl](../cad/stl/biped_platform/left_leg/ankle_mechanism/tibias2_rod_small.stl) | 1 |
| [tibias_actuation_ankle_12.stl](../cad/stl/biped_platform/left_leg/ankle_mechanism/tibias_actuation_ankle_12.stl) | 1 |
| [tibias_actuation_ankle_22.stl](../cad/stl/biped_platform/left_leg/ankle_mechanism/tibias_actuation_ankle_22.stl) | 1 |

### stl_to_print_right_leg
| name | quantity |
|---|---:|
| [bearing_spacer14_5_7_3.stl](../cad/stl/biped_platform/right_leg/ankle_mechanism/bearing_spacer14_5_7_3.stl) | 1 |
| [bearing_spacer24_5_7_3.stl](../cad/stl/biped_platform/right_leg/ankle_mechanism/bearing_spacer24_5_7_3.stl) | 1 |
| [bearing_spacer34_5_7_3.stl](../cad/stl/biped_platform/right_leg/ankle_mechanism/bearing_spacer34_5_7_3.stl) | 1 |
| [bearing_spacer44_5_7_3.stl](../cad/stl/biped_platform/right_leg/ankle_mechanism/bearing_spacer44_5_7_3.stl) | 1 |
| [tibias2_rod_long.stl](../cad/stl/biped_platform/right_leg/ankle_mechanism/tibias2_rod_long.stl) | 1 |
| [tibias2_rod_small.stl](../cad/stl/biped_platform/right_leg/ankle_mechanism/tibias2_rod_small.stl) | 1 |
| [tibias_actuation_ankle_12.stl](../cad/stl/biped_platform/right_leg/ankle_mechanism/tibias_actuation_ankle_12.stl) | 1 |
| [tibias_actuation_ankle_22.stl](../cad/stl/biped_platform/right_leg/ankle_mechanism/tibias_actuation_ankle_22.stl) | 1 |

## ankle

| category | name | specification | qty_subassembly | qty_robot |
|---|---|---|---:|---:|
| fastener_screw | M2.5 screw | M2.5 x 8 cyl head | 6 | 12 |
| fastener_axis | Shoulder screw 07534-05X40 | ISO7379, D1=5, L1=40, B=8, M4, SW=2.5, steel 12.9 | 1 | 2 |

### stl_to_print_left_leg
| name | quantity |
|---|---:|
| [ujoint_hat_small_12.stl](../cad/stl/biped_platform/left_leg/ankle/ujoint_hat_small_12.stl) | 1 |
| [ujoint_hat_small_22.stl](../cad/stl/biped_platform/left_leg/ankle/ujoint_hat_small_22.stl) | 1 |
| [ujoint_spacer_12_ujoint.stl](../cad/stl/biped_platform/left_leg/ankle/ujoint_spacer_12_ujoint.stl) | 1 |
| [ujoint_spacer_22_ujoint.stl](../cad/stl/biped_platform/left_leg/ankle/ujoint_spacer_22_ujoint.stl) | 1 |
| [ujoint_ujoint.stl](../cad/stl/biped_platform/left_leg/ankle/ujoint_ujoint.stl) | 1 |

### stl_to_print_right_leg
| name | quantity |
|---|---:|
| [ujoint_hat_small_12.stl](../cad/stl/biped_platform/right_leg/ankle/ujoint_hat_small_12.stl) | 1 |
| [ujoint_hat_small_22.stl](../cad/stl/biped_platform/right_leg/ankle/ujoint_hat_small_22.stl) | 1 |
| [ujoint_spacer_12_ujoint.stl](../cad/stl/biped_platform/right_leg/ankle/ujoint_spacer_12_ujoint.stl) | 1 |
| [ujoint_spacer_22_ujoint.stl](../cad/stl/biped_platform/right_leg/ankle/ujoint_spacer_22_ujoint.stl) | 1 |
| [ujoint_ujoint.stl](../cad/stl/biped_platform/right_leg/ankle/ujoint_ujoint.stl) | 1 |

## foot

| category | name | specification | qty_subassembly | qty_robot |
|---|---|---|---:|---:|
| bearing | Bearing | 5x16x5 | 2 | 4 |
| fastener_screw | M2.5 screw | M2.5 x 8 cyl head | 3 | 6 |
| fastener_nut | Nut M4 | M4 nut | 3 | 6 |

### stl_to_print_left_leg
| name | quantity |
|---|---:|
| [bearing_spacer14_5_7_3.stl](../cad/stl/biped_platform/left_leg/foot/bearing_spacer14_5_7_3.stl) | 1 |
| [bearing_spacer24_5_7_3.stl](../cad/stl/biped_platform/left_leg/foot/bearing_spacer24_5_7_3.stl) | 1 |
| [bearing_spacer34_5_7_3.stl](../cad/stl/biped_platform/left_leg/foot/bearing_spacer34_5_7_3.stl) | 1 |
| [bearing_spacer44_5_7_3.stl](../cad/stl/biped_platform/left_leg/foot/bearing_spacer44_5_7_3.stl) | 1 |
| [foot_foot.stl](../cad/stl/biped_platform/left_leg/foot/foot_foot.stl) | 1 |
| [foot_hat_small.stl](../cad/stl/biped_platform/left_leg/foot/foot_hat_small.stl) | 1 |

### stl_to_print_right_leg
| name | quantity |
|---|---:|
| [bearing_spacer14_5_7_3.stl](../cad/stl/biped_platform/right_leg/foot/bearing_spacer14_5_7_3.stl) | 1 |
| [bearing_spacer24_5_7_3.stl](../cad/stl/biped_platform/right_leg/foot/bearing_spacer24_5_7_3.stl) | 1 |
| [bearing_spacer34_5_7_3.stl](../cad/stl/biped_platform/right_leg/foot/bearing_spacer34_5_7_3.stl) | 1 |
| [bearing_spacer44_5_7_3.stl](../cad/stl/biped_platform/right_leg/foot/bearing_spacer44_5_7_3.stl) | 1 |
| [foot_foot.stl](../cad/stl/biped_platform/right_leg/foot/foot_foot.stl) | 1 |
| [foot_hat_small.stl](../cad/stl/biped_platform/right_leg/foot/foot_hat_small.stl) | 1 |

## assembly_pins

| category | name | specification | qty_subassembly | qty_robot |
|---|---|---|---:|---:|
| fastener_pin | Pin d3mm | d3 pin (goupille) | 4 | 8 |
| fastener_pin | Pin d4mm | d4 pin (goupille) | 9 | 18 |

## tools

| category | name | specification | qty_subassembly | qty_robot |
|---|---|---|---:|---:|
| tool | Allen key | 2.5 mm | 1 | 1 |

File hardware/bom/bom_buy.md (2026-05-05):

# BOM To Buy

## motors

| name | subassembly | qty_subassembly | qty_robot |
|---|---|---:|---:|
| RobStride O0 | torso | 2 | 2 |
| RobStride O2 | hipz | 1 | 2 |
| RobStride O3 | thigh | 2 | 4 |
| RobStride O5 | shin | 2 | 4 |

## torso

| category | name | specification | qty_subassembly | qty_robot |
|---|---|---|---:|---:|
| electronics_controller | Raspberry Pi 5 | single-board computer | 1 | 1 |
| electronics_imu | IMU | BNO055 or BNO085 | 1 | 1 |
| electronics_canfd_adapter | SAVVYCANFD 2CH CANFD adapter | USB, dual CAN FD, 12 Mbps max | 1 | 1 |
| cable_power | Power cable red | diameter >= 2.5 mm, 5 m | 1 | 1 |
| cable_power | Power cable black | diameter >= 2.5 mm, 5 m | 1 | 1 |
| cable_communication | Communication cable color 1 | 5 m | 1 | 1 |
| cable_communication | Communication cable color 2 | 5 m | 1 | 1 |
| motor | RobStride O0 | actuator | 2 | 2 |
| fastener_screw | M2 screw | M2 x 5 cyl head | 4 | 4 |
| fastener_screw | M2.5 screw | M2.5 x 20 cyl head | 9 | 9 |
| fastener_screw | M3 screw | M3 x 8 cyl head | 12 | 12 |
| fastener_screw | M4 screw | M4 x 20 cyl head | 16 | 16 |
| fastener_screw | M5 screw | M5 x 10 cyl head | 5 | 5 |

> Comment: cheaper or better CAN-FD adapters may exist, but this one is currently the only adapter proven in this project to handle the RobStride CAN protocol.

## hipx

| category | name | specification | qty_subassembly | qty_robot |
|---|---|---|---:|---:|
| fastener_screw | M3 screw | M3 x 8 cyl head | 3 | 6 |
| fastener_screw | M4 screw | M4 x 40 cyl head | 6 | 12 |
| fastener_screw | M4 screw | M4 x 45 cyl head | 9 | 18 |
| fastener_screw | M4 screw | M4 x 8 cyl head | 8 | 16 |

> Comment: the `hipx` M3 screw line is optional and can be removed without issue.

## hipz

| category | name | specification | qty_subassembly | qty_robot |
|---|---|---|---:|---:|
| motor | RobStride O2 | actuator | 1 | 2 |
| bearing | Bearing | 35x72x17 | 2 | 4 |
| fastener_screw | M4 screw | M4 x 10 cyl head | 8 | 16 |
| fastener_screw | M4 screw | M4 x 20 cyl head | 8 | 16 |

## thigh

| category | name | specification | qty_subassembly | qty_robot |
|---|---|---|---:|---:|
| motor | RobStride O3 | actuator | 2 | 4 |
| bearing | Bearing | 15x21x4 | 1 | 2 |
| bearing | Bearing | 5x16x5 | 2 | 4 |
| fastener_screw | M2.5 screw | M2.5 x 6 cyl head | 3 | 6 |
| fastener_screw | M4 screw | M4 x 10 cyl head | 4 | 8 |
| fastener_screw | M4 screw | M4 x 23.5 cyl head | 4 | 8 |
| fastener_screw | M4 screw | M4 x 8 cyl head | 10 | 20 |
| fastener_axis | Shoulder screw 07534-05X40 | ISO7379, D1=5, L1=40, B=8, M4, SW=2.5, steel 12.9 | 1 | 2 |

## knee_mechanism

| category | name | specification | qty_subassembly | qty_robot |
|---|---|---|---:|---:|
| bearing | Bearing | 15x21x4 | 2 | 4 |
| fastener_screw | M3 screw | M3 x 12.5 cyl head | 3 | 6 |
| fastener_screw | M4 screw | M4 x 16 cyl head | 8 | 16 |

## shin

| category | name | specification | qty_subassembly | qty_robot |
|---|---|---|---:|---:|
| motor | RobStride O5 | actuator | 2 | 4 |
| bearing | Bearing | 15x21x4 | 4 | 8 |
| fastener_screw | M2.5 screw | M2.5 x 8 cyl head | 3 | 6 |
| fastener_screw | M3 screw | M3 x 17.5 cyl head | 4 | 8 |
| fastener_screw | M3 screw | M3 x 10 cyl head | 24 | 48 |
| fastener_screw | M4 screw | M4 x 18 cyl head | 16 | 32 |
| fastener_screw | M4 screw | M4 x 10 cyl head | 9 | 18 |
| fastener_nut | Nut M4 | M4 nut | 3 | 6 |
| fastener_insert | Heat-set insert M3 | brass threaded insert M3 | 4 | 8 |

## ankle_mechanism

| category | name | specification | qty_subassembly | qty_robot |
|---|---|---|---:|---:|
| fastener_screw | M5 screw | M5 x 15 cyl head | 4 | 8 |
| joint_spherical | Spherical joint 27628-01-05 | Norelem | 4 | 8 |
| fastener_axis | Shoulder screw 07534-05X20 | ISO7379, D1=5, L1=20, B=8, M4, steel 12.9 | 4 | 8 |

## ankle

| category | name | specification | qty_subassembly | qty_robot |
|---|---|---|---:|---:|
| fastener_screw | M2.5 screw | M2.5 x 8 cyl head | 6 | 12 |
| fastener_axis | Shoulder screw 07534-05X40 | ISO7379, D1=5, L1=40, B=8, M4, SW=2.5, steel 12.9 | 1 | 2 |

## foot

| category | name | specification | qty_subassembly | qty_robot |
|---|---|---|---:|---:|
| bearing | Bearing | 5x16x5 | 2 | 4 |
| fastener_screw | M2.5 screw | M2.5 x 8 cyl head | 3 | 6 |
| fastener_nut | Nut M4 | M4 nut | 3 | 6 |

## assembly_pins

| category | name | specification | qty_subassembly | qty_robot |
|---|---|---|---:|---:|
| fastener_pin | Pin d3mm | d3 pin (goupille) | 4 | 8 |
| fastener_pin | Pin d4mm | d4 pin (goupille) | 9 | 18 |

## tools

| category | name | specification | qty_subassembly | qty_robot |
|---|---|---|---:|---:|
| tool | Allen key | 2.5 mm | 1 | 1 |

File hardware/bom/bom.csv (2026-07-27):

subassembly | category | name | specification | qty_subassembly | qty_robot
torso | electronics_controller | Raspberry Pi 5 | single-board computer | 1 | 1
torso | electronics_imu | IMU | BNO055 or BNO085 | 1 | 1
torso | electronics_canfd_adapter | SAVVYCANFD 2CH CANFD adapter | USB, dual CAN FD, 12 Mbps max | 1 | 1
torso | cable_power | Power cable red | diameter >= 2.5 mm, 5 m | 1 | 1
torso | cable_power | Power cable black | diameter >= 2.5 mm, 5 m | 1 | 1
torso | cable_communication | Communication cable color 1 | 5 m | 1 | 1
torso | cable_communication | Communication cable color 2 | 5 m | 1 | 1
torso | motor | RobStride O0 | actuator | 2 | 2
torso | fastener_screw | M2 screw | M2 x 5 cyl head | 4 | 4
torso | fastener_screw | M2.5 screw | M2.5 x 20 cyl head | 9 | 9
torso | fastener_screw | M3 screw | M3 x 8 cyl head | 12 | 12
torso | fastener_screw | M4 screw | M4 x 20 cyl head | 16 | 16
torso | fastener_screw | M5 screw | M5 x 10 cyl head | 5 | 5
torso | stl_print | torso/torso_can_holder.stl | stl | 1 | 1
torso | stl_print | torso/torso_can_holder_2.stl | stl | 1 | 1
torso | stl_print | torso/torso_imu_holder.stl | stl | 1 | 1
torso | stl_print | torso/torso_torso13.stl | stl | 1 | 1
torso | stl_print | torso/torso_torso23.stl | stl | 1 | 1
torso | stl_print | torso/torso_torso33.stl | stl | 1 | 1
torso | stl_print | torso/torso_uper_torso_22.stl | stl | 1 | 1
torso | stl_print | torso/torso_upper_torso_12.stl | stl | 1 | 1
hipx | fastener_screw | M3 screw | M3 x 8 cyl head | 3 | 6
hipx | fastener_screw | M4 screw | M4 x 40 cyl head | 6 | 12
hipx | fastener_screw | M4 screw | M4 x 45 cyl head | 9 | 18
hipx | fastener_screw | M4 screw | M4 x 8 cyl head | 8 | 16
hipx | stl_print | left_leg/hipx/hipx_2_hipxy_sym.stl | stl | 1 | 1
hipx | stl_print | right_leg/hipx/hipx_2_hipxy.stl | stl | 1 | 1
hipz | motor | RobStride O2 | actuator | 1 | 2
hipz | bearing | Bearing | 35x72x17 | 2 | 4
hipz | fastener_screw | M4 screw | M4 x 10 cyl head | 8 | 16
hipz | fastener_screw | M4 screw | M4 x 20 cyl head | 8 | 16
hipz | stl_print | left_leg/hipz/hip_z_hipz12_sym.stl | stl | 1 | 1
hipz | stl_print | left_leg/hipz/hip_z_hipz22_sym.stl | stl | 1 | 1
hipz | stl_print | right_leg/hipz/hip_z_hipz12.stl | stl | 1 | 1
hipz | stl_print | right_leg/hipz/hip_z_hipz22.stl | stl | 1 | 1
thigh | motor | RobStride O3 | actuator | 2 | 4
thigh | bearing | Bearing | 15x21x4 | 1 | 2
thigh | bearing | Bearing | 5x16x5 | 2 | 4
thigh | fastener_screw | M2.5 screw | M2.5 x 6 cyl head | 3 | 6
thigh | fastener_screw | M4 screw | M4 x 10 cyl head | 4 | 8
thigh | fastener_screw | M4 screw | M4 x 23.5 cyl head | 4 | 8
thigh | fastener_screw | M4 screw | M4 x 8 cyl head | 10 | 20
thigh | fastener_axis | Shoulder screw 07534-05X40 | ISO7379, D1=5, L1=40, B=8, M4, SW=2.5, steel 12.9 | 1 | 2
thigh | stl_print | left_leg/thigh/femur_v2_femur_12_sym_1.stl | stl | 1 | 1
thigh | stl_print | left_leg/thigh/femur_v2_femur_22_sym_1.stl | stl | 1 | 1
thigh | stl_print | left_leg/thigh/femur_v2_hat_femur_2.stl | stl | 1 | 1
thigh | stl_print | right_leg/thigh/femur_v2_femur_12_1.stl | stl | 1 | 1
thigh | stl_print | right_leg/thigh/femur_v2_femur_22_1.stl | stl | 1 | 1
thigh | stl_print | right_leg/thigh/femur_v2_hat_femur_2.stl | stl | 1 | 1
knee_mechanism | bearing | Bearing | 15x21x4 | 2 | 4
knee_mechanism | fastener_screw | M3 screw | M3 x 12.5 cyl head | 3 | 6
knee_mechanism | fastener_screw | M4 screw | M4 x 16 cyl head | 8 | 16
knee_mechanism | stl_print | left_leg/knee_mechanism/femur_v2_knee_actuation_2.stl | stl | 1 | 1
knee_mechanism | stl_print | left_leg/knee_mechanism/femur_v2_knee_rod12_sym_1.stl | stl | 1 | 1
knee_mechanism | stl_print | left_leg/knee_mechanism/femur_v2_knee_rod22_sym_1.stl | stl | 1 | 1
knee_mechanism | stl_print | right_leg/knee_mechanism/femur_v2_knee_actuation_1.stl | stl | 1 | 1
knee_mechanism | stl_print | right_leg/knee_mechanism/femur_v2_knee_rod12_1.stl | stl | 1 | 1
knee_mechanism | stl_print | right_leg/knee_mechanism/femur_v2_knee_rod22_1.stl | stl | 1 | 1
shin | motor | RobStride O5 | actuator | 2 | 4
shin | bearing | Bearing | 15x21x4 | 4 | 8
shin | fastener_screw | M2.5 screw | M2.5 x 8 cyl head | 3 | 6
shin | fastener_screw | M3 screw | M3 x 17.5 cyl head | 4 | 8
shin | fastener_screw | M3 screw | M3 x 10 cyl head | 24 | 48
shin | fastener_screw | M4 screw | M4 x 18 cyl head | 16 | 32
shin | fastener_screw | M4 screw | M4 x 10 cyl head | 9 | 18
shin | fastener_nut | Nut M4 | M4 nut | 3 | 6
shin | fastener_insert | Heat-set insert M3 | brass threaded insert M3 | 4 | 8
shin | stl_print | left_leg/shin/spacer12_5_9_4_5.stl | stl | 1 | 1
shin | stl_print | left_leg/shin/spacer22_5_9_4_5.stl | stl | 1 | 1
shin | stl_print | left_leg/shin/tibias2_hat_big.stl | stl | 1 | 1
shin | stl_print | left_leg/shin/tibias2_shin_spacer_2.stl | stl | 1 | 1
shin | stl_print | left_leg/shin/tibias2_tibias12_sym_4.stl | stl | 1 | 1
shin | stl_print | left_leg/shin/tibias2_tibias22_sym_4.stl | stl | 1 | 1
shin | stl_print | right_leg/shin/spacer12_5_9_4_5.stl | stl | 1 | 1
shin | stl_print | right_leg/shin/spacer22_5_9_4_5.stl | stl | 1 | 1
shin | stl_print | right_leg/shin/tibias2_hat_big.stl | stl | 1 | 1
shin | stl_print | right_leg/shin/tibias2_shin_spacer_2.stl | stl | 1 | 1
shin | stl_print | right_leg/shin/tibias2_tibias12.stl | stl | 1 | 1
shin | stl_print | right_leg/shin/tibias2_tibias22.stl | stl | 1 | 1
ankle_mechanism | fastener_screw | M5 screw | M5 x 15 cyl head | 4 | 8
ankle_mechanism | joint_spherical | Spherical joint 27628-01-05 | Norelem | 4 | 8
ankle_mechanism | fastener_axis | Shoulder screw 07534-05X20 | ISO7379, D1=5, L1=20, B=8, M4, steel 12.9 | 4 | 8
ankle_mechanism | stl_print | left_leg/ankle_mechanism/bearing_spacer14_5_7_3.stl | stl | 1 | 1
ankle_mechanism | stl_print | left_leg/ankle_mechanism/bearing_spacer24_5_7_3.stl | stl | 1 | 1
ankle_mechanism | stl_print | left_leg/ankle_mechanism/bearing_spacer34_5_7_3.stl | stl | 1 | 1
ankle_mechanism | stl_print | left_leg/ankle_mechanism/bearing_spacer44_5_7_3.stl | stl | 1 | 1
ankle_mechanism | stl_print | left_leg/ankle_mechanism/tibias2_rod_long.stl | stl | 1 | 1
ankle_mechanism | stl_print | left_leg/ankle_mechanism/tibias2_rod_small.stl | stl | 1 | 1
ankle_mechanism | stl_print | left_leg/ankle_mechanism/tibias_actuation_ankle_12.stl | stl | 1 | 1
ankle_mechanism | stl_print | left_leg/ankle_mechanism/tibias_actuation_ankle_22.stl | stl | 1 | 1
ankle_mechanism | stl_print | right_leg/ankle_mechanism/bearing_spacer14_5_7_3.stl | stl | 1 | 1
ankle_mechanism | stl_print | right_leg/ankle_mechanism/bearing_spacer24_5_7_3.stl | stl | 1 | 1
ankle_mechanism | stl_print | right_leg/ankle_mechanism/bearing_spacer34_5_7_3.stl | stl | 1 | 1
ankle_mechanism | stl_print | right_leg/ankle_mechanism/bearing_spacer44_5_7_3.stl | stl | 1 | 1
ankle_mechanism | stl_print | right_leg/ankle_mechanism/tibias2_rod_long.stl | stl | 1 | 1
ankle_mechanism | stl_print | right_leg/ankle_mechanism/tibias2_rod_small.stl | stl | 1 | 1
ankle_mechanism | stl_print | right_leg/ankle_mechanism/tibias_actuation_ankle_12.stl | stl | 1 | 1
ankle_mechanism | stl_print | right_leg/ankle_mechanism/tibias_actuation_ankle_22.stl | stl | 1 | 1
ankle | fastener_screw | M2.5 screw | M2.5 x 8 cyl head | 6 | 12
ankle | fastener_axis | Shoulder screw 07534-05X40 | ISO7379, D1=5, L1=40, B=8, M4, SW=2.5, steel 12.9 | 1 | 2
ankle | stl_print | left_leg/ankle/ujoint_hat_small_12.stl | stl | 1 | 1
ankle | stl_print | left_leg/ankle/ujoint_hat_small_22.stl | stl | 1 | 1
ankle | stl_print | left_leg/ankle/ujoint_spacer_12_ujoint.stl | stl | 1 | 1
ankle | stl_print | left_leg/ankle/ujoint_spacer_22_ujoint.stl | stl | 1 | 1
ankle | stl_print | left_leg/ankle/ujoint_ujoint.stl | stl | 1 | 1
ankle | stl_print | right_leg/ankle/ujoint_hat_small_12.stl | stl | 1 | 1
ankle | stl_print | right_leg/ankle/ujoint_hat_small_22.stl | stl | 1 | 1
ankle | stl_print | right_leg/ankle/ujoint_spacer_12_ujoint.stl | stl | 1 | 1
ankle | stl_print | right_leg/ankle/ujoint_spacer_22_ujoint.stl | stl | 1 | 1
ankle | stl_print | right_leg/ankle/ujoint_ujoint.stl | stl | 1 | 1
foot | bearing | Bearing | 5x16x5 | 2 | 4
foot | fastener_screw | M2.5 screw | M2.5 x 8 cyl head | 3 | 6
foot | fastener_nut | Nut M4 | M4 nut | 3 | 6
foot | stl_print | left_leg/foot/bearing_spacer14_5_7_3.stl | stl | 1 | 1
foot | stl_print | left_leg/foot/bearing_spacer24_5_7_3.stl | stl | 1 | 1
foot | stl_print | left_leg/foot/bearing_spacer34_5_7_3.stl | stl | 1 | 1
foot | stl_print | left_leg/foot/bearing_spacer44_5_7_3.stl | stl | 1 | 1
foot | stl_print | left_leg/foot/foot_foot.stl | stl | 1 | 1
foot | stl_print | left_leg/foot/foot_hat_small.stl | stl | 1 | 1
foot | stl_print | right_leg/foot/bearing_spacer14_5_7_3.stl | stl | 1 | 1
foot | stl_print | right_leg/foot/bearing_spacer24_5_7_3.stl | stl | 1 | 1
foot | stl_print | right_leg/foot/bearing_spacer34_5_7_3.stl | stl | 1 | 1
foot | stl_print | right_leg/foot/bearing_spacer44_5_7_3.stl | stl | 1 | 1
foot | stl_print | right_leg/foot/foot_foot.stl | stl | 1 | 1
foot | stl_print | right_leg/foot/foot_hat_small.stl | stl | 1 | 1
assembly_pins | fastener_pin | Pin d3mm | d3 pin (goupille) | 4 | 8
assembly_pins | fastener_pin | Pin d4mm | d4 pin (goupille) | 9 | 18
tools | tool | Allen key | 2.5 mm | 1 | 1

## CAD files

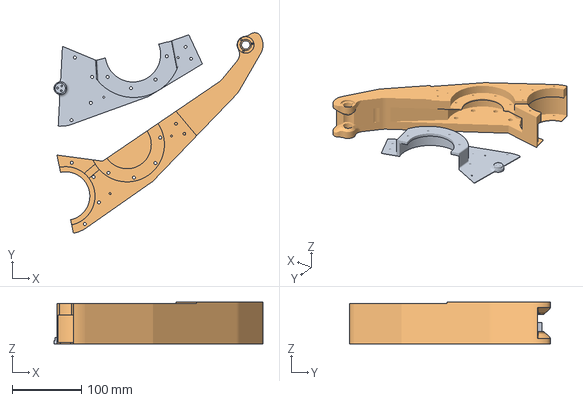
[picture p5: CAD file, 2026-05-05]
docs/manufacturing/h2d_profiles/thigh_femur_example.3mf
302.2 x 290.0 x 60.0 mm
femur_v2 - femur_22_sym(1).stl
femur_v2 - femur_12_sym(1).stl

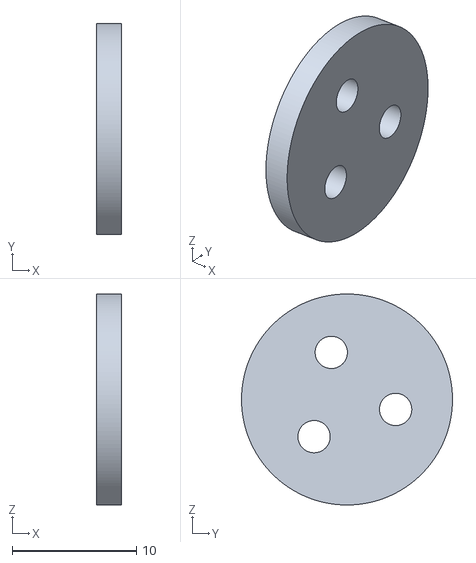
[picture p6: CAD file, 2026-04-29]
hardware/cad/stl/biped_platform/left_leg/ankle/ujoint_hat_small_12.stl
2.00 x 17.0 x 17.0

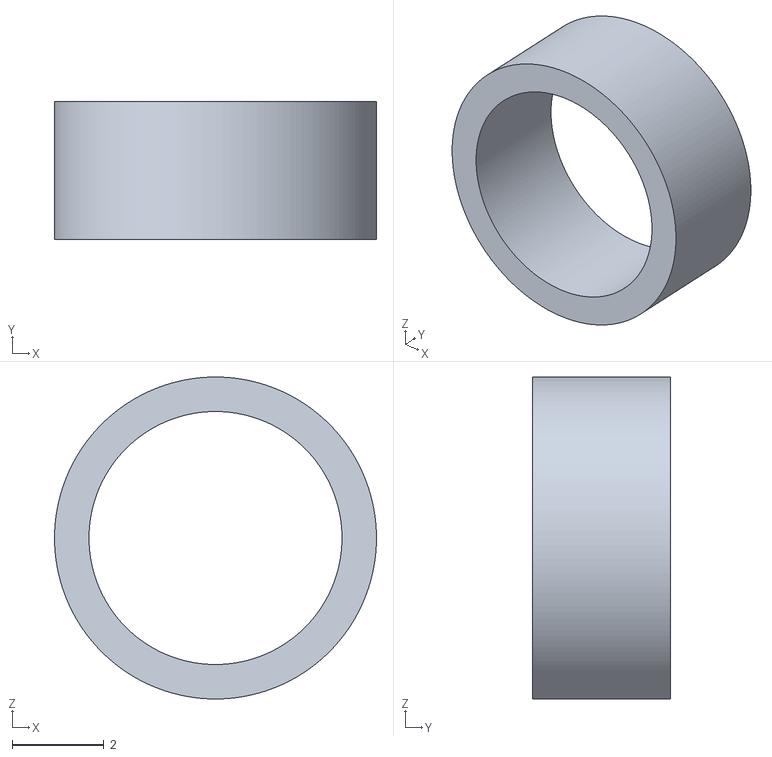
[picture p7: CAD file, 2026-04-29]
hardware/cad/stl/biped_platform/left_leg/ankle_mechanism/bearing_spacer14_5_7_3.stl
7.00 x 3.00 x 7.00

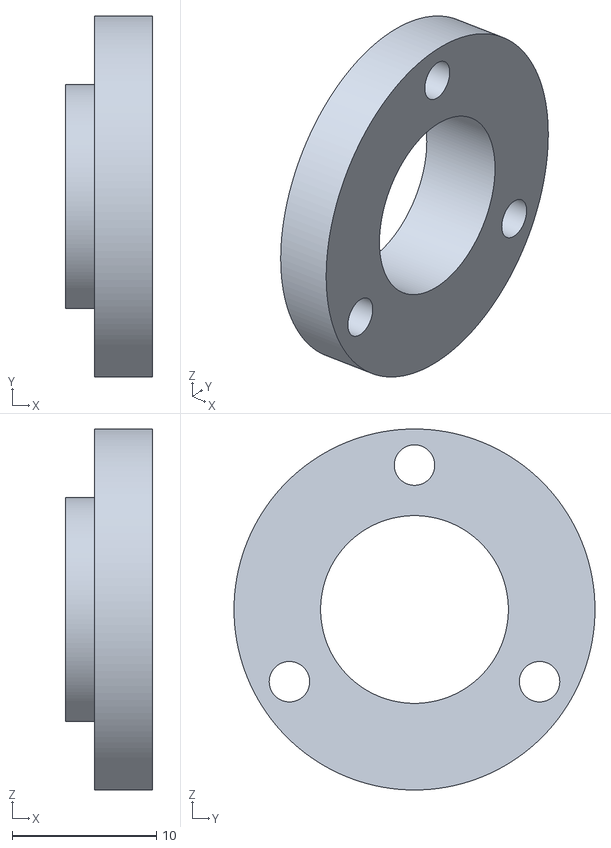
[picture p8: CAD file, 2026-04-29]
hardware/cad/stl/biped_platform/left_leg/foot/foot_hat_small.stl
6.00 x 25.0 x 25.0

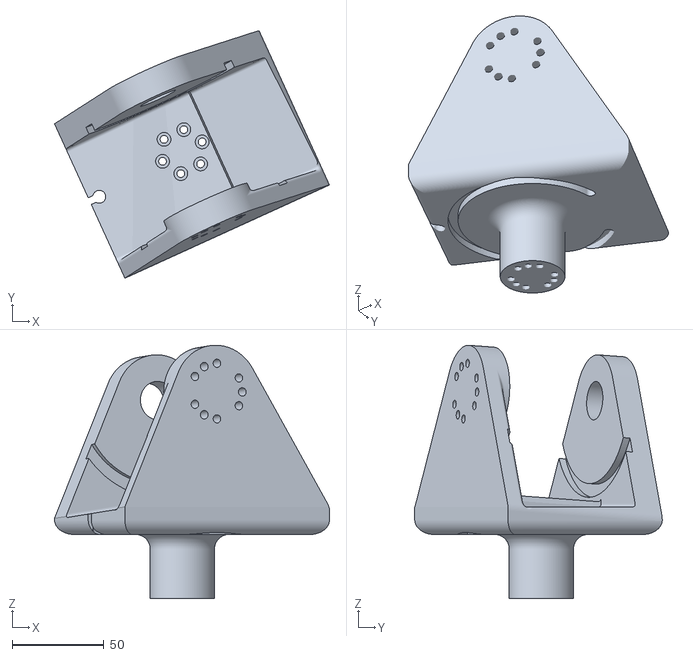
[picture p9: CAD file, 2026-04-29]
hardware/cad/stl/biped_platform/left_leg/hipx/hipx_2_hipxy_sym.stl
149.7 x 134.8 x 138.0

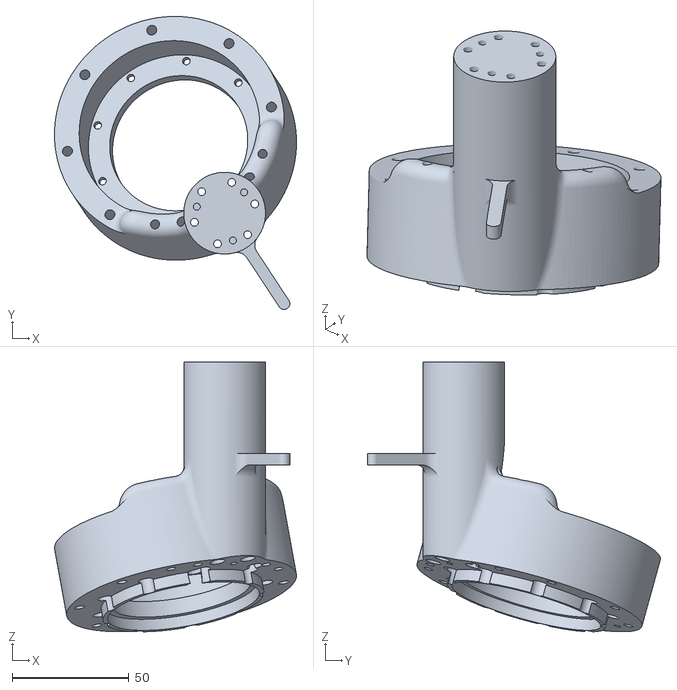
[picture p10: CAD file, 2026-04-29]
hardware/cad/stl/biped_platform/left_leg/hipz/hip_z_hipz22_sym.stl
103.7 x 125.5 x 115.5

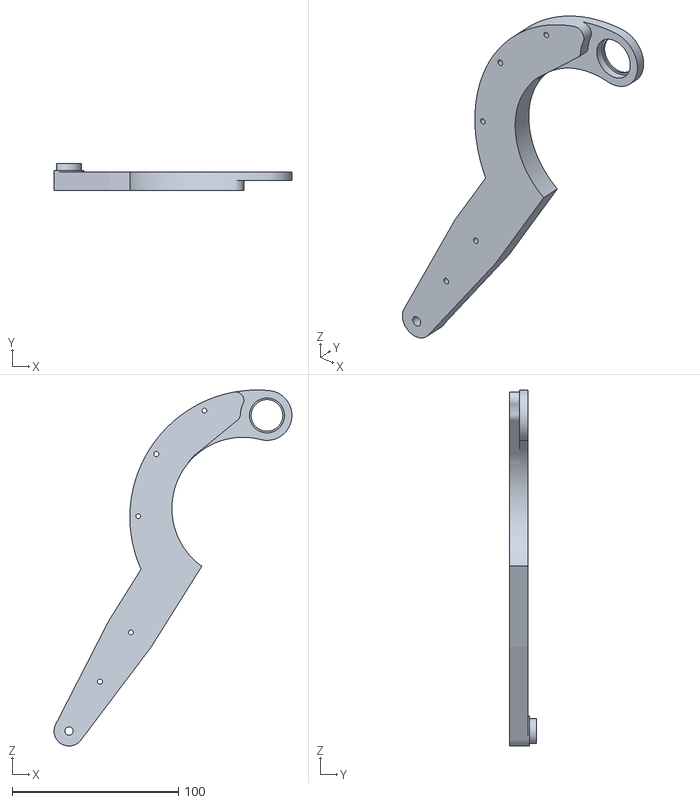
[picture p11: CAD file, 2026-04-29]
hardware/cad/stl/biped_platform/left_leg/knee_mechanism/femur_v2_knee_rod22_sym_1.stl
143.0 x 16.0 x 214.1

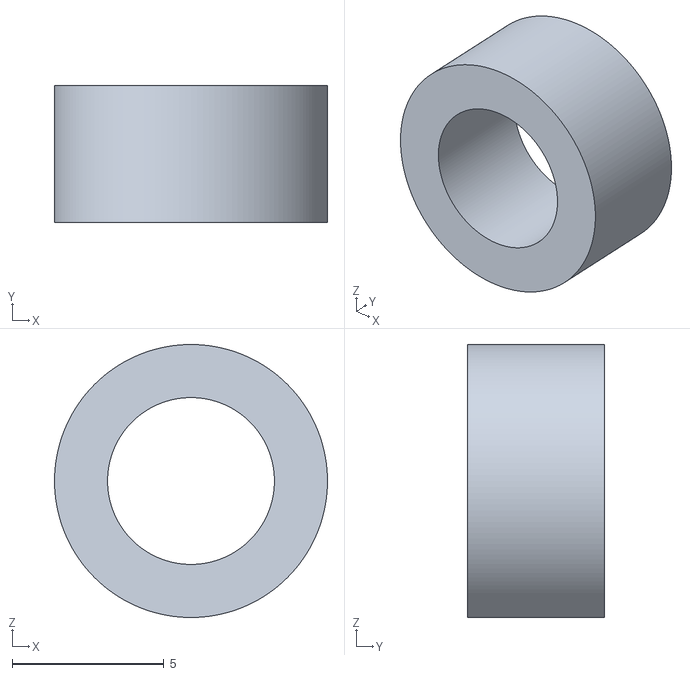
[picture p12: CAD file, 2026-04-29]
hardware/cad/stl/biped_platform/left_leg/shin/spacer12_5_9_4_5.stl
9.00 x 4.50 x 9.00

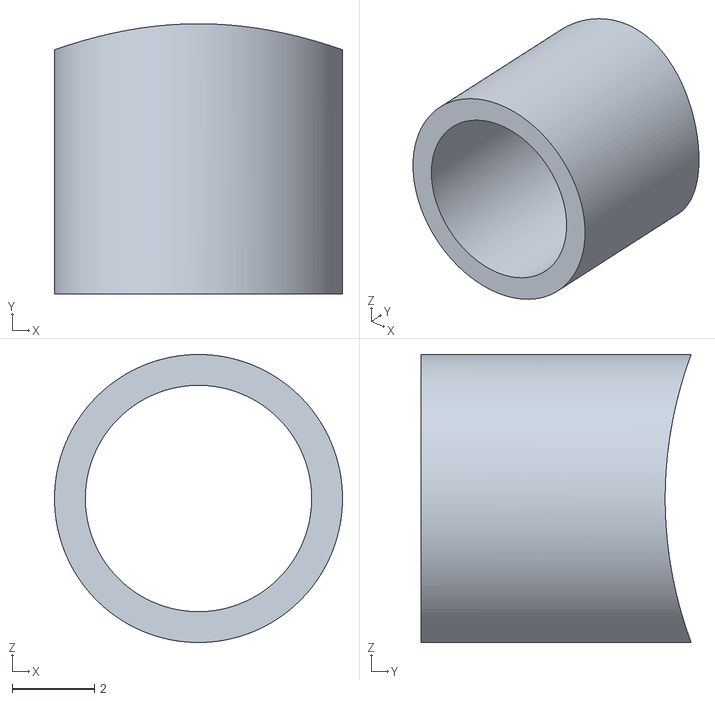
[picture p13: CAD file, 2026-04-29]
hardware/cad/stl/biped_platform/right_leg/ankle/ujoint_spacer_12_ujoint.stl
7.00 x 6.57 x 7.00

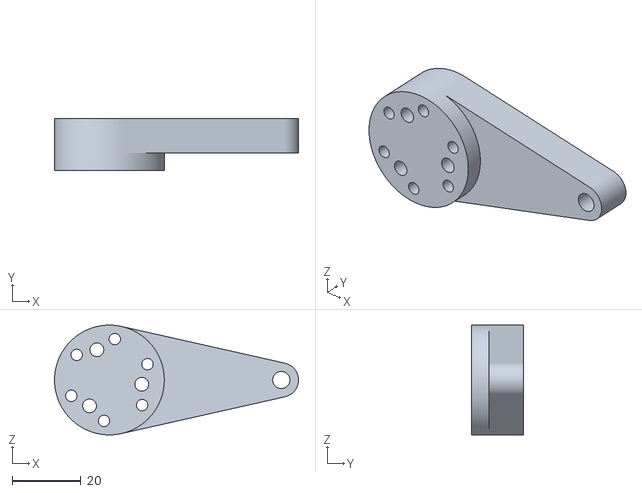
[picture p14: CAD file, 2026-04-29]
hardware/cad/stl/biped_platform/right_leg/ankle_mechanism/tibias_actuation_ankle_12.stl
71.0 x 15.0 x 31.9

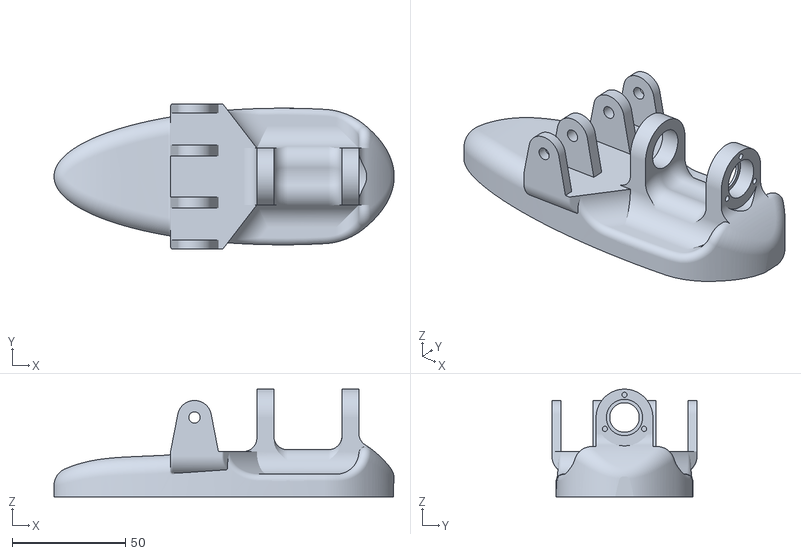
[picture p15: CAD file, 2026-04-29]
hardware/cad/stl/biped_platform/right_leg/foot/foot_foot.stl
149.9 x 64.0 x 47.5

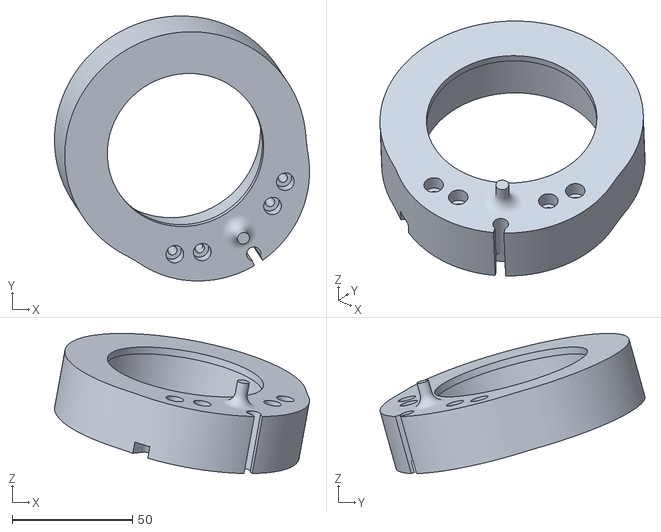
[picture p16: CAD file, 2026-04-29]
hardware/cad/stl/biped_platform/right_leg/hipz/hip_z_hipz22.stl
106.2 x 110.3 x 58.3

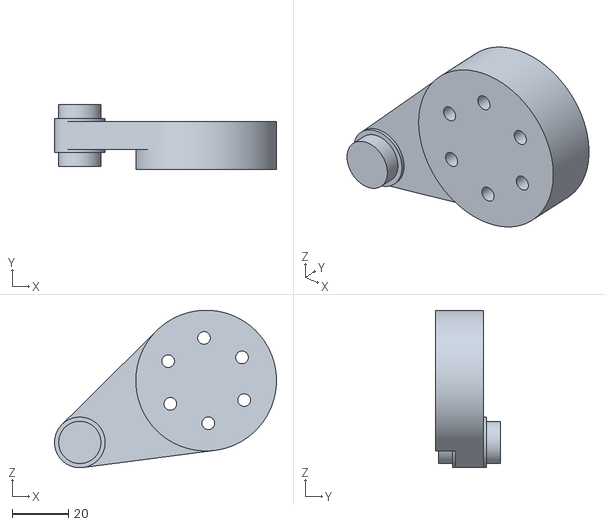
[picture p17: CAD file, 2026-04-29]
hardware/cad/stl/biped_platform/right_leg/knee_mechanism/femur_v2_knee_actuation_1.stl
78.9 x 23.0 x 56.0

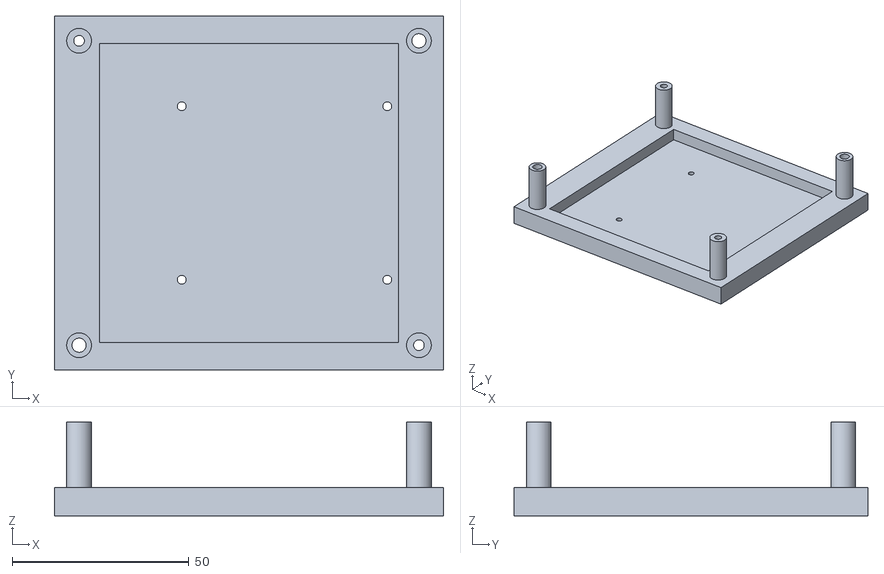
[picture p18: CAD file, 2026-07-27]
hardware/cad/stl/biped_platform/torso/torso_can_holder_2.stl
110.0 x 100.0 x 26.6

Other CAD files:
hardware/cad/stl/biped_platform/left_leg/thigh/femur_hat_small_1.stl
hardware/cad/stl/biped_platform/right_leg/hipx/hipx_2_hipxy.stl
hardware/cad/stl/biped_platform/right_leg/thigh/femur_hat_small_1.stl
docs/manufacturing/h2d_profiles/hip_example.3mf
docs/manufacturing/h2d_profiles/shin_tibias_example.3mf
hardware/cad/stl/biped_platform/left_leg/ankle/ujoint_ujoint.stl
hardware/cad/stl/biped_platform/left_leg/ankle_mechanism/tibias2_rod_long.stl
hardware/cad/stl/biped_platform/left_leg/ankle_mechanism/tibias2_rod_small.stl
hardware/cad/stl/biped_platform/left_leg/hipz/hip_z_hipz12_sym.stl
hardware/cad/stl/biped_platform/left_leg/knee_mechanism/femur_v2_knee_rod12_sym_1.stl
hardware/cad/stl/biped_platform/left_leg/shin/femur_v2_hat_femur_2.stl
hardware/cad/stl/biped_platform/left_leg/shin/tibias2_hat_big.stl
hardware/cad/stl/biped_platform/left_leg/shin/tibias2_shin_spacer_2.stl
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

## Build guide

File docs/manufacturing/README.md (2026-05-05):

# Manufacturing

Manufacturing notes for biped-platform parts.

Files:
- `docs/manufacturing/printing_guide.md`
- `docs/manufacturing/h2d_profiles/` (Bambu H2D `.3mf` references + print screenshots for key parts)
- `docs/manufacturing/h2d_profiles/README.md`
- `hardware/bom/bom.csv`
- `hardware/bom/bom_buy.csv`

STL location:
- `hardware/cad/stl/biped_platform/<side>/<subassembly>/`

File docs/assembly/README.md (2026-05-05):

# Assembly

This directory contains step-by-step assembly instructions for biped-platform subassemblies.

Inputs used for assembly writing:
- STL layout: `hardware/cad/stl/biped_platform/`
- Total BOM (includes STL): `hardware/bom/bom.csv`
- Buy BOM (no STL): `hardware/bom/bom_buy.csv`
- Main assembly guide: `docs/assembly/assembly_guide.md`
- Motor commissioning workflow: `docs/electronics/motor_commissioning.md`
- Printing list: `docs/manufacturing/printing_guide.md`
- Assembly photos: `docs/assembly/photos/`

Recommended structure per assembly doc:
- prerequisites (printed parts, hardware, tools)
- step-by-step operations
- fastener callouts per step
- quality checks at the end of each step

Current mapping:
- `docs/assembly/subassembly_map.md`

Guide set:
- `assembly_guide.md`: ordered build sequence + per-subassembly components + key assembly constraints
- `assembly_guide_outline.md`: compact sequence reference

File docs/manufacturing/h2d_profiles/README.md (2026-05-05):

# Bambu H2D Print References

Reference `.3mf` projects and screenshots for the most critical printed parts.

Files:
- `shin_tibias_example.3mf` + `shin_tibias_print_example.png`: shin/tibias print setup.
- `thigh_femur_example.3mf` + `thigh_print_example.png`: thigh/femur print setup.
- `hip_example.3mf` + `hip_print_example.png`: hip print setup.

Scope note:
- These references are provided for `shin`, `thigh`, and `hip` only.
- Other parts are generally straightforward with the baseline settings from `docs/manufacturing/printing_guide.md`.

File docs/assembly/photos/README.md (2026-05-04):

# Assembly Photos (Mounted Robot)

This folder stores mounted-robot reference photos used by the assembly guide.

## File map

- `leg_full_view.jpg`: full leg overall context.
- `torso_detail.jpg`: torso assembly details.
- `hipy_detail.jpg`: hipy-side detail (hipz naming in repo).
- `hipz_detail.jpg`: hipz detail.
- `thigh_detail.jpg`: thigh/femur detail.
- `knee_detail.jpg`: close-up knee detail.
- `knee_mechanism_view_1.jpg`: knee mechanism angle 1.
- `knee_mechanism_view_2.jpg`: knee mechanism angle 2.
- `knee_mechanism_view_3.jpg`: knee mechanism angle 3.

Use these photos as visual context, and always cross-check final orientation against the Onshape assembly.

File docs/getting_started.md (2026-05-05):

# Getting Started

## 1. Clone repository

```bash
git clone <repo-url>
cd lerobot-humanoid-hardware
```

## 2. Read scope and safety first

- `README.md`
- `docs/overview.md`
- `docs/safety.md`

## 3. Preferred startup order (new build)

1. Order buy parts from `hardware/bom/bom_buy.csv`.
2. Print all STL parts from `docs/manufacturing/printing_guide.md`.
3. Commission and check all motors before assembly (`docs/electronics/motor_commissioning.md`).
4. Assemble the robot (`docs/assembly/assembly_guide.md`).
5. Run wiring checks and first power-on runbook (`docs/electronics/check_wiring.md`, `docs/electronics/first_power_on.md`).

## 4. Pick your task flow

- Assembly work: start with `docs/assembly/`
- Manufacturing work: start with `docs/manufacturing/`
- Electronics work: start with `docs/electronics/`

## 5. Runtime dependency

Full robot runtime and model live at:
- https://github.com/Virgileboat/lerobot-humanoid-runtime

`commission_motor.py` in this repo is self-contained and does not require runtime/toolkit imports.

## 6. Commission motors before assembly (required before mechanical assembly)

Detailed procedure: `docs/electronics/motor_commissioning.md`

Guided flow:

```bash
python hardware/config/commission_motor.py wizard --channel can0
```

This wizard can:
- detect motor protocol and ID
- switch to MIT protocol with reboot checkpoints
- assign final motor ID from model ID map
- run motor motion check (`0 deg -> 90 deg for 1 s -> 0 deg -> disable`)

## 7. Before first power-on

Follow both runbooks:
- `docs/electronics/check_wiring.md`
- `docs/electronics/first_power_on.md`

## 8. Support

If you are blocked:
- `virgilebatto@gmail.com`

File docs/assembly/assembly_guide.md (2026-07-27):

# Assembly Guide

Assembly order:
1. Configure all motors (`docs/electronics/motor_commissioning.md`).
2. Print all STL parts (`docs/manufacturing/printing_guide.md`).
3. Build upper legs in order: `torso -> hips (left and right) -> thigh (left and right)`.
4. Assemble upper and lower leg modules.
5. Integrate both legs to torso and run wiring checks.

Common assembly rules:
- For each subassembly, insert bearings first (press or gentle hammer).
- Place motor metal pin during the same phase as bearing insertion.
- Exception: in `knee_mechanism` and `ankle`, one interface should stay slightly loose but still movable.
- For subassembly pins: place them during assembly except on `thigh` (keep thigh demountable).
- Motor orientation is critical: follow the Onshape assembly orientation relative to each motor connector, otherwise cable length can become insufficient.
- Default thread strategy is direct screw in plastic; use around `5 Nm` for non-structural plastic threads.
- For motor threaded holes and structural insert zones, use higher torque appropriate to the thread/material.
- Some fits are intentionally tight; if required, gently ream/drill with a metal bit at low speed.
- Pins are not a standalone assembly stage: install them inside each motor/subassembly during build.
- Tools are prerequisites only (not assemblies).

Reference files:
# TODO Update BoM for simplified instructions
- `hardware/bom/bom.csv`
- `hardware/bom/bom_buy.csv`
- `docs/manufacturing/printing_guide.md`
- `docs/electronics/motor_commissioning.md`
- `hardware/electronics/cabling/README.md`

# TODO Get a wiring diagram
Leg cabling note:
- Left and right legs use the same sub-cable design and routing logic.
- Cable legend: red = power, green = CAN, blue = CAN + power.

Leg cabling integration order (both legs):
1. Prepare three sub-cables using `hardware/electronics/cabling/README.md`: shin, thigh, hip pass-through.
2. Install the shin sub-cable during `shin` assembly, before final closure.
3. Install the thigh sub-cable during `thigh` assembly, before final tightening.
4. Route the hip pass-through sub-cable during `hipz` integration.
5. Join leg cables to torso harness during final leg-to-torso integration.

Spacer coverage check:
- Spacers are documented via STL lists in each relevant subassembly section.
- Spacer STL subassemblies: `shin`, `ankle_mechanism`, `ankle`, `foot`.
- Non-spacer STL subassemblies: `torso`, `hipx`, `hipz`, `thigh`, `knee_mechanism`.

Mounted robot photo references (explicit names):
- `docs/assembly/photos/leg_full_view.jpg`
- `docs/assembly/photos/torso_detail.jpg`
- `docs/assembly/photos/hipy_detail.jpg`
- `docs/assembly/photos/hipz_detail.jpg`
- `docs/assembly/photos/thigh_detail.jpg`
- `docs/assembly/photos/knee_detail.jpg`
- `docs/assembly/photos/knee_mechanism_view_1.jpg`
- `docs/assembly/photos/knee_mechanism_view_2.jpg`
- `docs/assembly/photos/knee_mechanism_view_3.jpg`

## Torso

Components:
| Category | Name | Specification | Qty / Subassembly | Qty / Robot |
|---|---|---|---:|---:|
| electronics_controller | Raspberry Pi 5 | single-board computer | 1 | 1 |
| electronics_imu | IMU | BNO055 or BNO085 | 1 | 1 |
| electronics_canfd_adapter | SAVVYCANFD 2CH CANFD adapter | USB, dual CAN FD, 12 Mbps max | 1 | 1 |
| cable_power | Power cable red | diameter >= 2.5 mm, 5 m | 1 | 1 |
| cable_power | Power cable black | diameter >= 2.5 mm, 5 m | 1 | 1 |
| cable_communication | Communication cable color 1 | 5 m | 1 | 1 |
| cable_communication | Communication cable color 2 | 5 m | 1 | 1 |
| motor | RobStride O0 | actuator | 2 | 2 |
| fastener_screw | M2 screw | M2 x 5 cyl head | 4 | 4 |
| fastener_screw | M2.5 screw | M2.5 x 20 cyl head | 9 | 9 |
| fastener_screw | M3 screw | M3 x 8 cyl head | 12 | 12 |
| fastener_screw | M4 screw | M4 x 20 cyl head | 16 | 16 |
| fastener_screw | M5 screw | M5 x 10 cyl head | 5 | 5 |
| fastener_screw | M3 screw | M3 x 35 cyl head | 4 | 4 |
| bearing | Bearing | 35x72x17 | 2 | 2 |

STL To Print:
| Name | Quantity |
|---|---:|
| torso/torso_can_holder.stl | 1 |
| torso/torso_imu_holder.stl | 1 |
| torso/torso_torso13.stl | 1 |
| torso/torso_torso23.stl | 1 |
| torso/torso_torso33.stl | 1 |
| torso/torso_upper_torso_22.stl | 1 |
| torso/torso_upper_torso_12.stl | 1 |

> Comment: cheaper or better CAN-FD adapters may exist, but this one is currently the only adapter proven in this project to handle the RobStride CAN protocol.

Assembly steps:
Before starting, it's important to note that the torso motor supports have a directionality to them. Ensure that the assembly will align the ports on each motors towards the inside of the robot by aligning the screw holes as shown below. Notice that one of the inner screw holes should align with the slot in torso13.

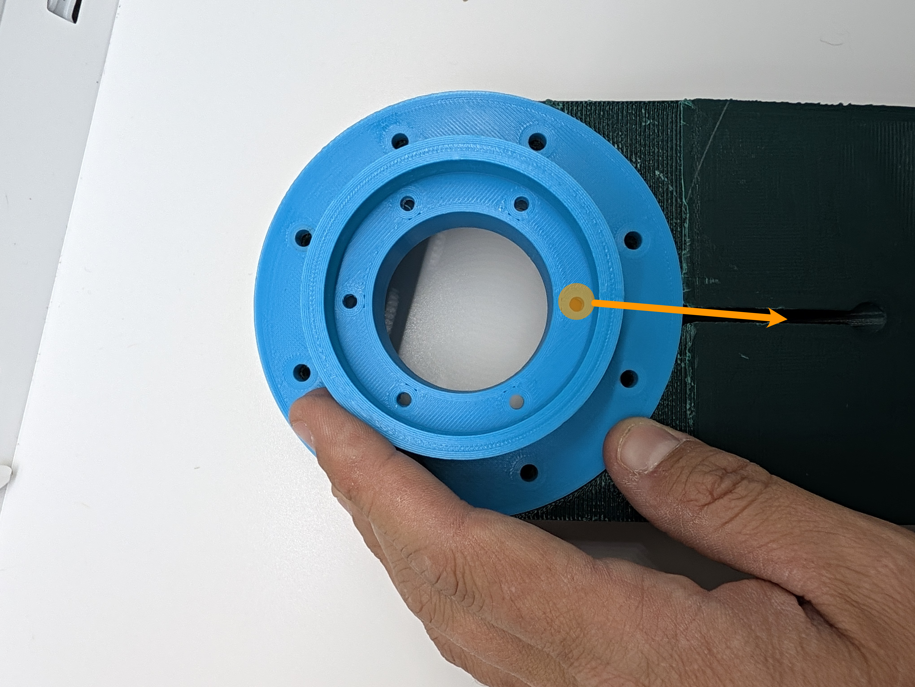
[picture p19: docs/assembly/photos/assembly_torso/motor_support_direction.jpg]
Assembly Torso directionality


1. Place the two RobStride O0 motors into their respective motor support (torso_torso23 and torso_torso33). Secure each with six M3x8 screws.

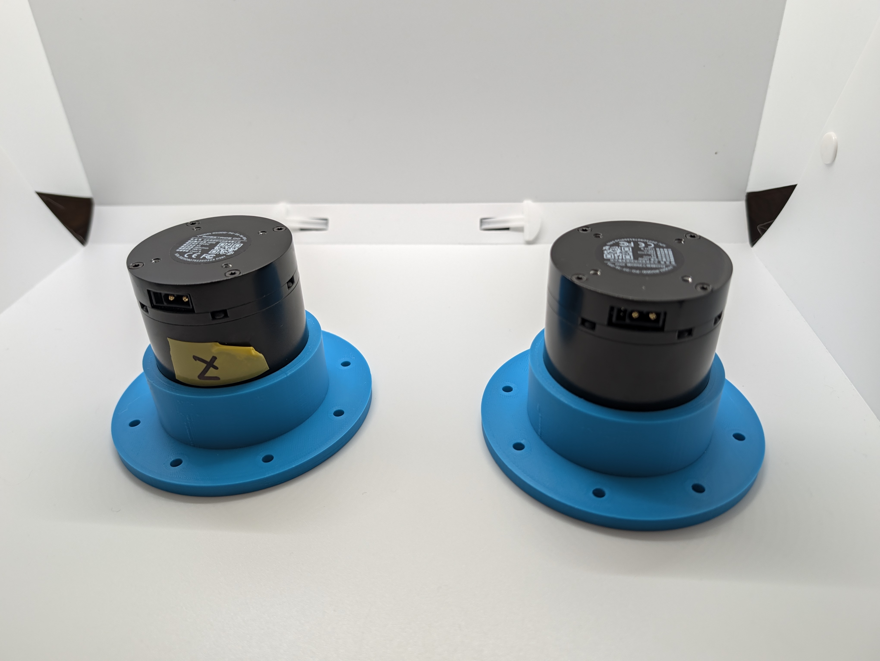
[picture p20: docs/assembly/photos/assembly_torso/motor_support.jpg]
Assembly Torso


2. Insert two 35x72x17 bearings into the slots on torso_13.stl

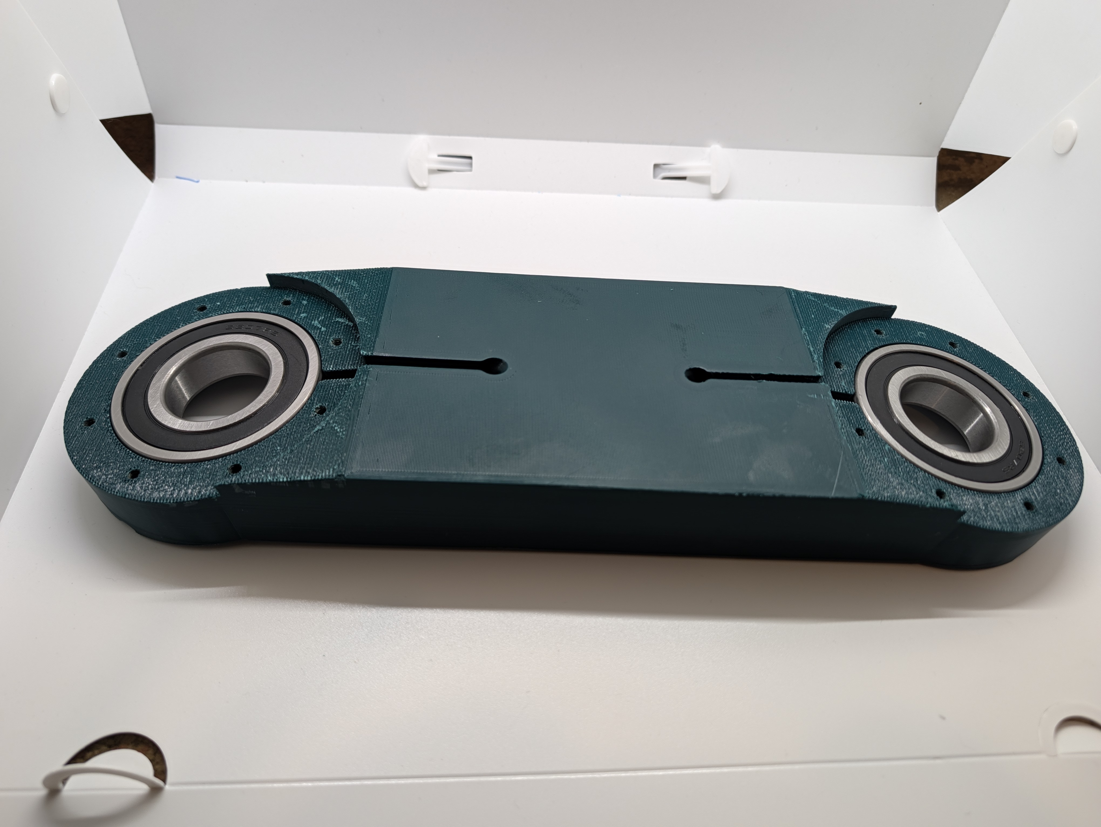
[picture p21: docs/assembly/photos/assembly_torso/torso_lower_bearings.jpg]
Assembly Torso Bearings


3. Place each motor-support subassembly on top of the bearing stack and secure them with eight M4x20 screws. At this stage ensure that the motor cables face inward.

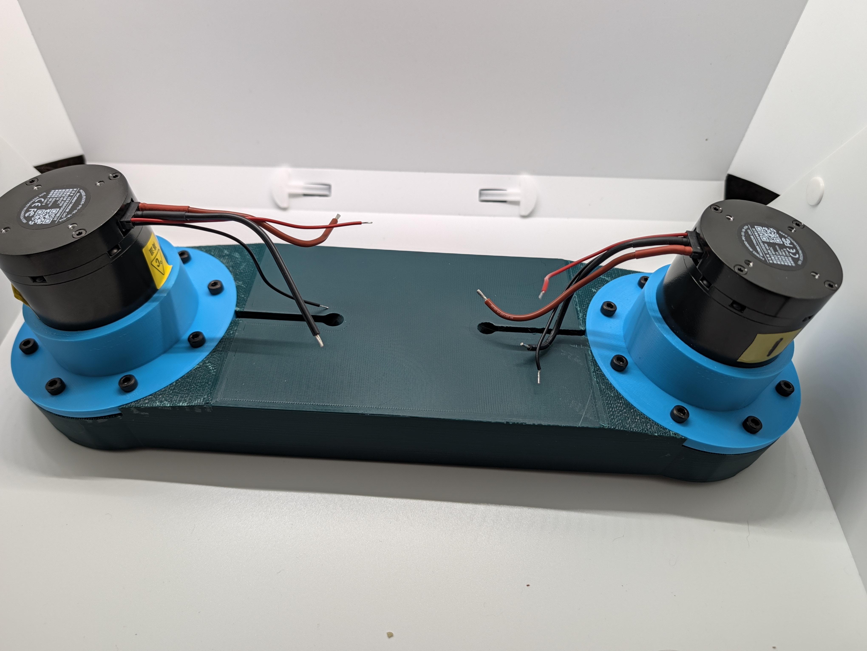
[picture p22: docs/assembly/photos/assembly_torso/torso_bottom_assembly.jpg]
Lower Torso Assembly


4. Verify both torso motor outputs rotate freely after tightening.

5. Attach the CAN bus holder to the bottom of the assembly. This will not be secured using screws, but the part on the buttom extending from the base will fit in the lower assembly's groove.

6. Place the CAN bus on the CAN bus holder and use torso_can_holder_2.stl to secure it into place with four M3x35 screws.

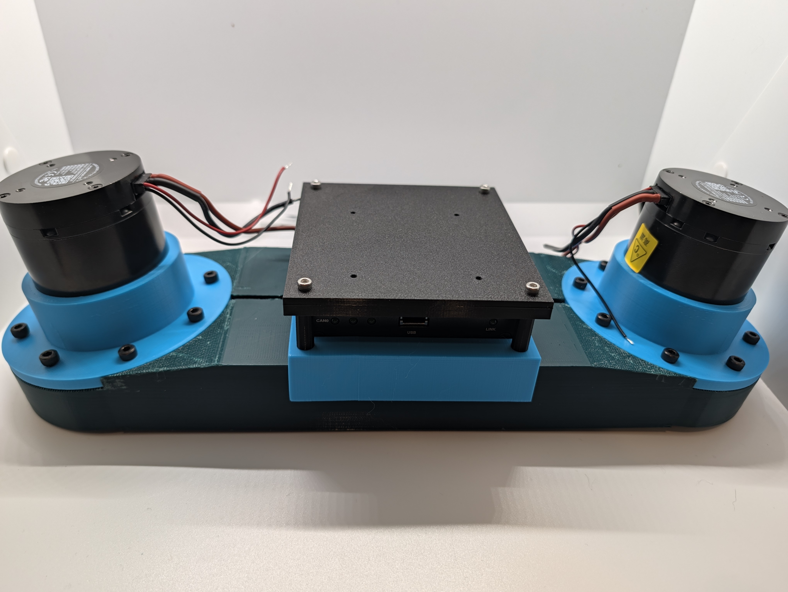
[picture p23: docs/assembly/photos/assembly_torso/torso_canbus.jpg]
Torso CAN Bus Assembly


7. Use five M5x10 screws to connect torso_upper_torso_22 with torso_upper_torso_12. The two on the ends should be loosely inserted as they will be tightened in the next step.

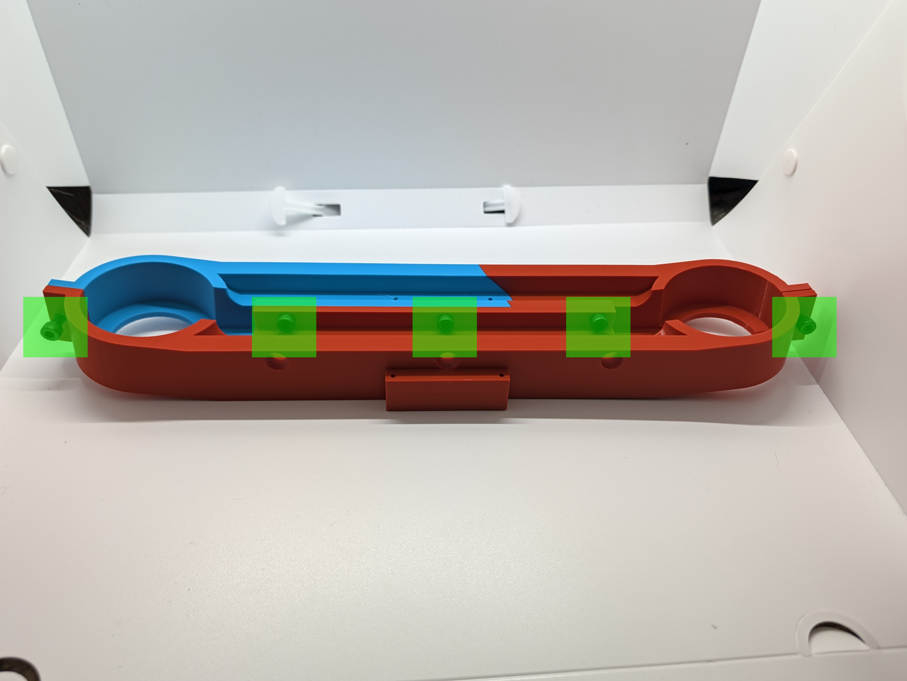
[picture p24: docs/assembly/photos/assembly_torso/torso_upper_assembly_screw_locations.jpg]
Lower Torso Assembly


8. Place the upper assembly on to the lower assembly and tighten the screws at the end of the upper assembly.

9. Attach the Raspberry Pi with the IMU holder to the top of the upper assembly using four M2.5x20 screws. *Do not overtighten, as there's no extra space under the Raspberry Pi and you can damage the board*. Attach the IMU to the top of the IMU holder using four M2x5 screws. Pins on the IMU should be soldered so that the pins protrude from the 'front' of the board.

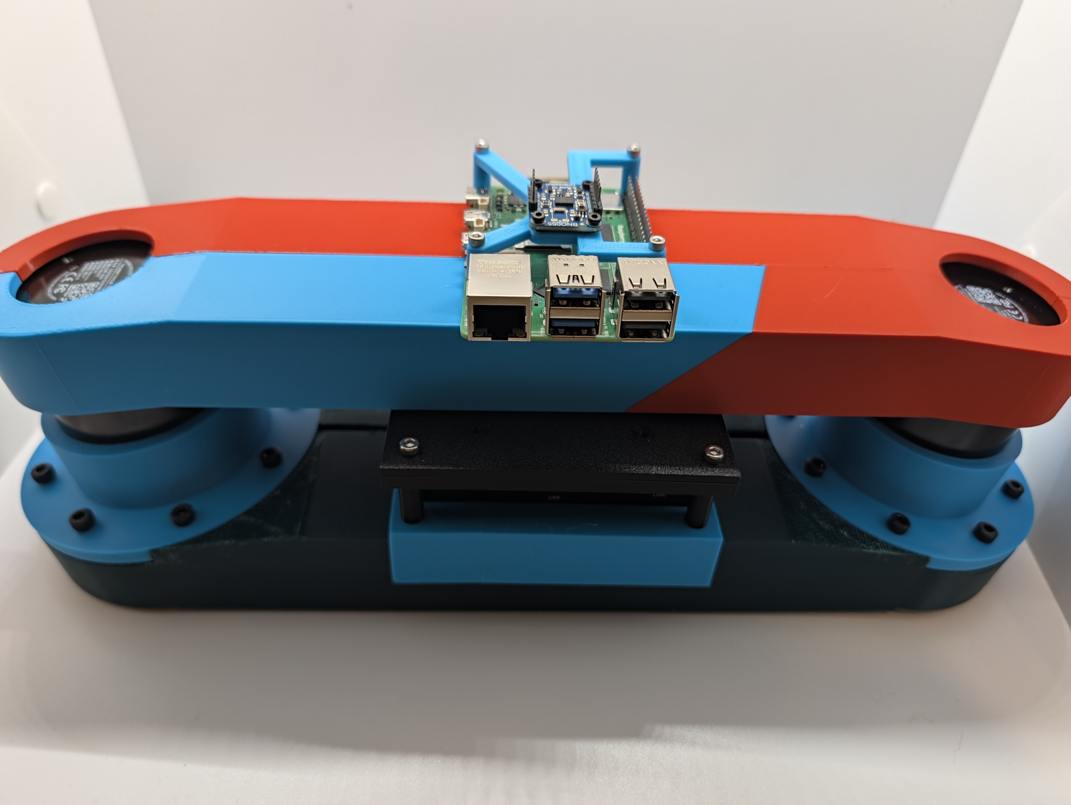
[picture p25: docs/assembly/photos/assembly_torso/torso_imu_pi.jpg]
Lower Torso Assembly


## Hips

Components:
| Category | Name | Specification | Qty / Subassembly | Qty / Robot |
|---|---|---|---:|---:|
| motor | RobStride O2 | actuator | 1 | 2 |
| bearing | Bearing | 35x72x17 | 2 | 4 |
| fastener_screw | M3 screw | M3 x 10 cyl head | 12 | 24 |
| fastener_screw | M4 screw | M4 x 12 cyl head | 6 | 12 |
| fastener_screw | M4 screw | M4 x 40 cyl head | 6 | 12 |
| fastener_screw | M4 screw | M4 x 45 cyl head | 4 | 8 |

STL To Print:
| Name | Quantity |
|---|---:|
| left_leg/hipz/hip_z_hipz12_sym.stl | 1 |
| left_leg/hipz/hip_z_hipz22_sym.stl | 1 |
| right_leg/hipz/hip_z_hipz12.stl | 1 |
| right_leg/hipz/hip_z_hipz22.stl | 1 |
| left_leg/hipx/hipx_2_hipxy_sym.stl | 1 |
| right_leg/hipx/hipx_2_hipxy.stl | 1 |

Assembly steps:
1. Insert the 35x72x17 bearings into hip_z_hipz22 and hip_z_hipz22_sym

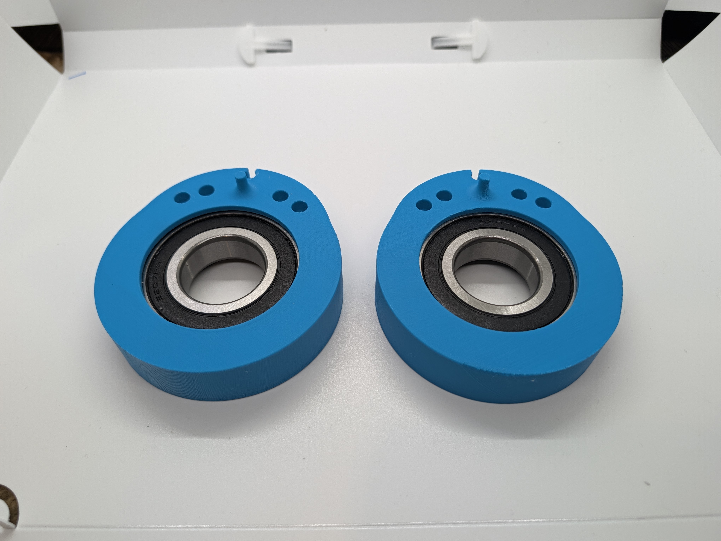
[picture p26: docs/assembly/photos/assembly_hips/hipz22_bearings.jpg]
Hipz 22 with Bearing


2. Insert the RobStride O2 motors into hip_z_hipz12 and hip_z_hipz12_sym. Double check which hip piece you are inserting your motors into. 

> Comment: It is difficult to rotate the entire motor body or remove the motor after insertion, so confirm hole alignment before setting.

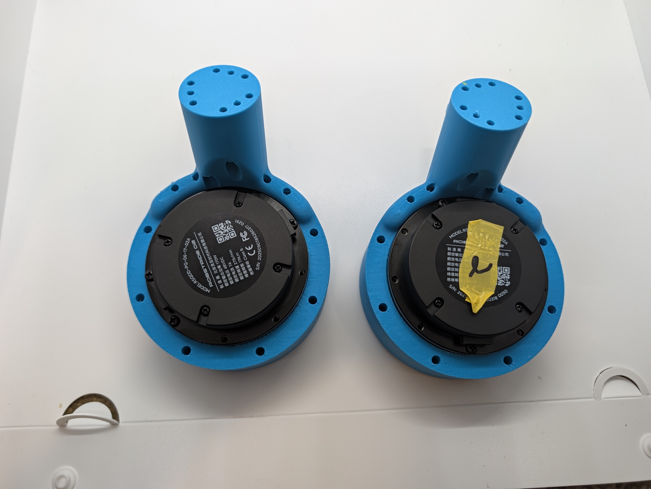
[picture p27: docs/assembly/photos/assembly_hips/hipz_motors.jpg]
Hipz 12 with Motors


3. Use nine M3x10 screws to attach the RobStride O2 motor to hipz12 and hipz12_sym, respectively.

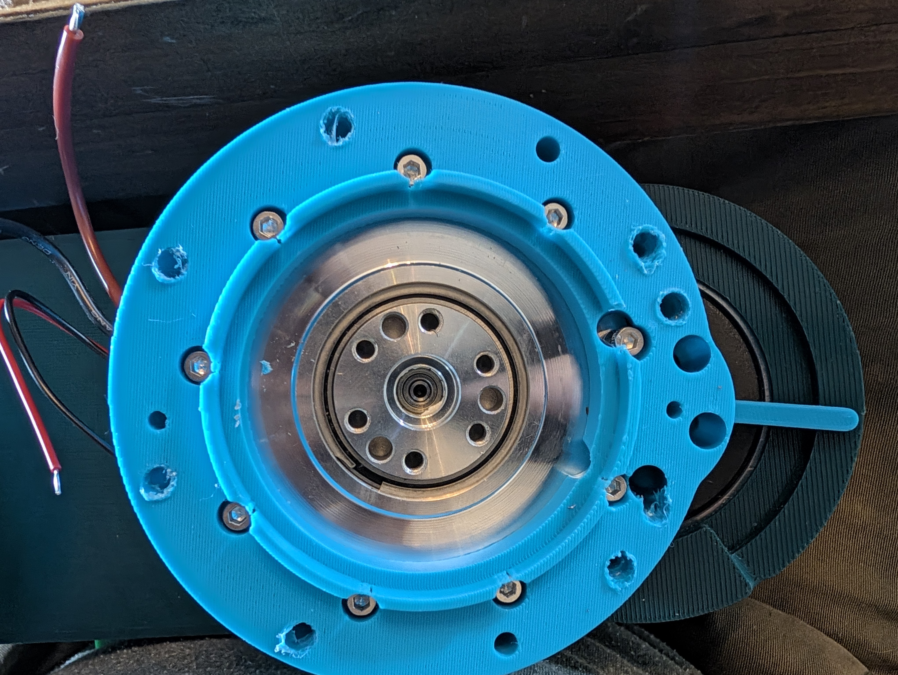
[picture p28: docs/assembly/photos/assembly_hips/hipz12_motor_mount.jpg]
Hipz 12 Motor Mount


4. Attach hip_z_hipz12 and hip_z_hipz12_sym to motor 1 or 7, respectively, using three M3x10 screws and three pins. 

> Comment: You will need a longer hex key than what comes with most screw sets. I had success with a 13cm key.

> Comment: The hip pieces have spaces for six screws (also shown in the CAD file), but if the hip piece is attached to the torso without the motor in it, the motor cannot fit into place. If the motor is placed into the hip piece, three of the screw holes are covered. This is an open item for fixing in the future.

> Comment: The thin piece extending from hipz12 should sit to the side of a blocking piece on the torso track, preventing the hip from rotating 360 degrees (in theory, they also break off if too much force applied).

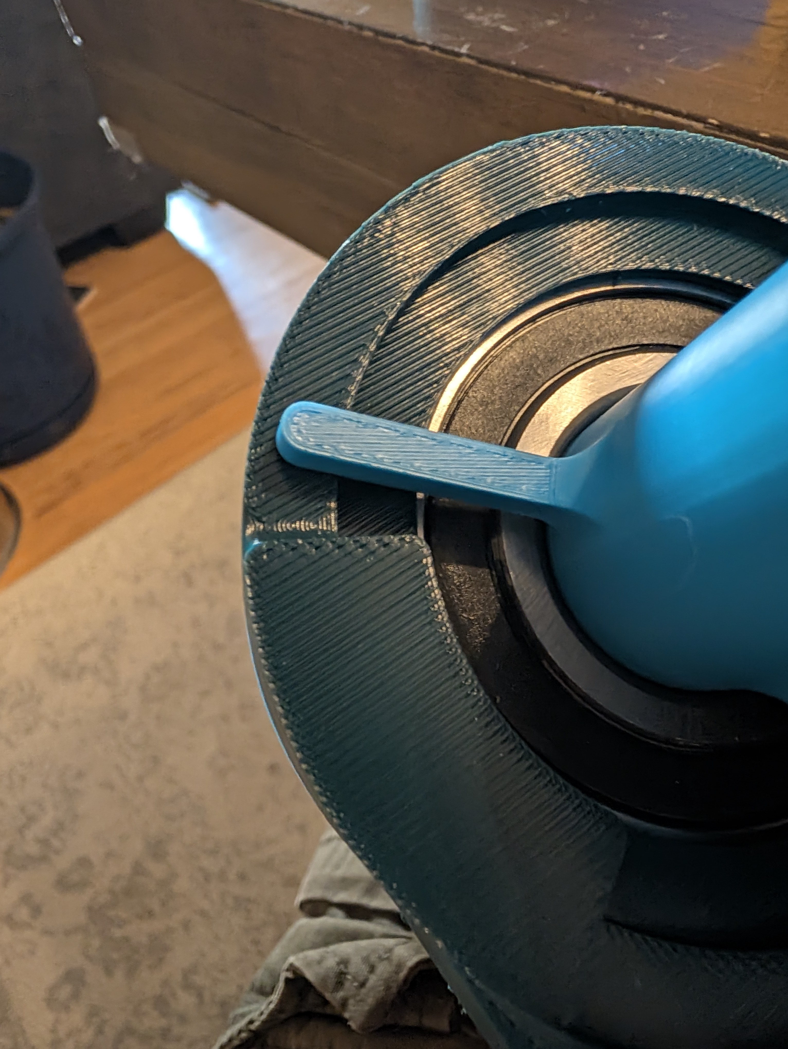
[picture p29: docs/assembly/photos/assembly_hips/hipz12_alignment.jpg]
Hipz 12 Motor Alignment


5. Route the hip pass-through sub-cable through hipz according to `hardware/electronics/cabling/README.md`.

6. Attach hipz22 and hipz22_sym to hipz12 and hipz12_sym. Use four M4x45 screws on the lower side and six M4x40 screws on the top side to attach them together.

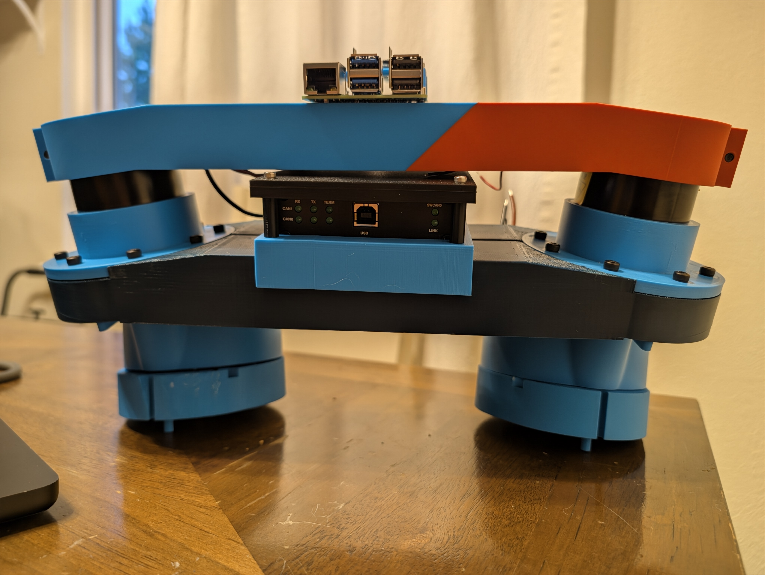
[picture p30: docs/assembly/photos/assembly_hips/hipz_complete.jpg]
Hipz Complete


7. Insert hipx_2_hipxy and hipx_2_hipxy_sym into their respective points from the hip z assemblies that you just completed. Mount each to the RobStride O2 motor using six M4x12 screws.

8. Verify free motion. There may be a slight clicking from the long piece extending from hipz12/hipz12_sym and the notch on the bottom of the lower torso.

At this point you should have a completed upper for the legs robot.

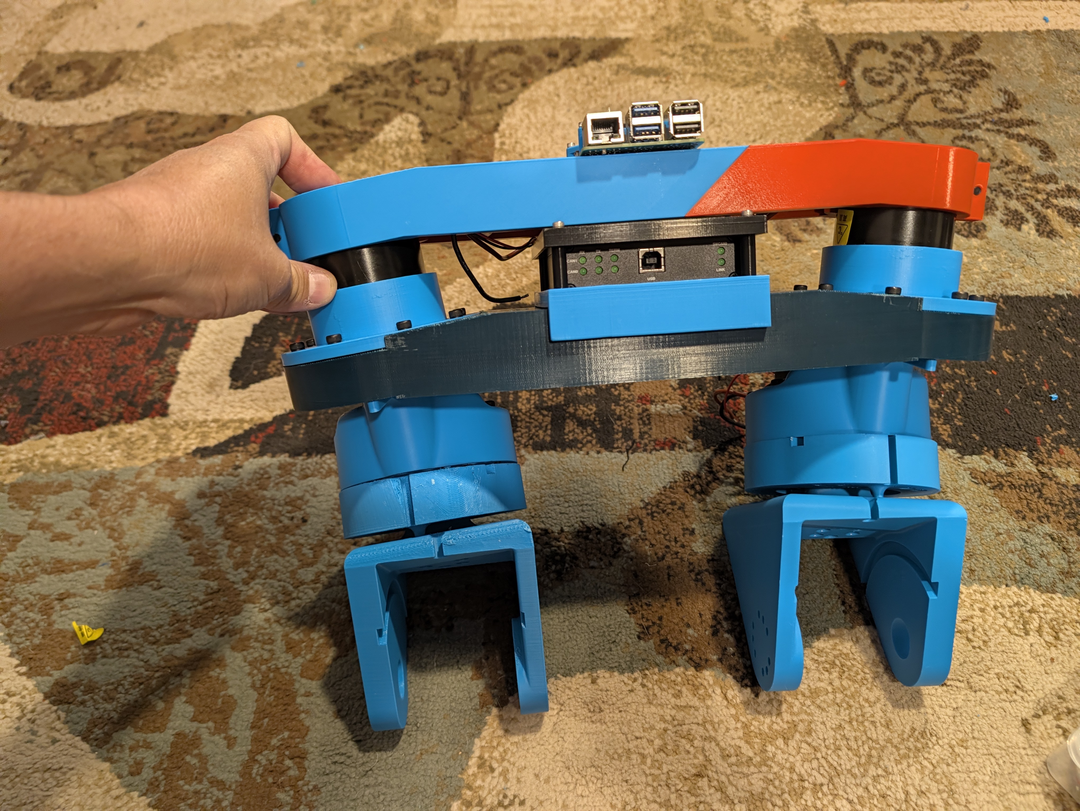
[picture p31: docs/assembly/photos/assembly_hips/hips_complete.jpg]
Hipz Complete


## thigh

Components:
| Category | Name | Specification | Qty / Subassembly | Qty / Robot |
|---|---|---|---:|---:|
| motor | RobStride O3 | actuator | 2 | 4 |
| bearing | Bearing | 15x21x4 | 1 | 2 |
| fastener_screw | M2.5 screw | M2.5 x 6 cyl head | 3 | 6 |
| fastener_screw | M4 screw | M4 x 10 cyl head | 12 | 24 |
| fastener_screw | M4 screw | M4 x 16 cyl head | 2 | 4 |
| fastener_screw | M4 screw | M4 x 20 cyl head | 6 | 12 |
| fastener_screw | M4 screw | M4 x 30 cyl head | 4 | 8 |
| fastener_insert | Heat-set insert M4 | brass threaded insert M4 | 2 | 4 |

STL To Print:
| Name | Quantity |
|---|---:|
| left_leg/thigh/femur_v2_femur_12_sym_1.stl | 1 |
| left_leg/thigh/femur_v2_femur_22_sym_1.stl | 1 |
| left_leg/thigh/femur_hat_small_1.stl | 1 |
| right_leg/thigh/femur_v2_femur_12_1.stl | 1 |
| right_leg/thigh/femur_v2_femur_22_1.stl | 1 |
| right_leg/thigh/femur_hat_small_1.stl | 1 |

> Comment: The left leg follows the same instructions as the right, though uses the symetrical pieces. They can be built concurrently.

Assembly steps:
1. Insert one 15x21x4 bearing into the joint hole on `hipxy`.

> Comment: This is a difficult piece to insert. I applied WD-40 to the bearing slot and gently tapped it into position with the flat side of a hammer.

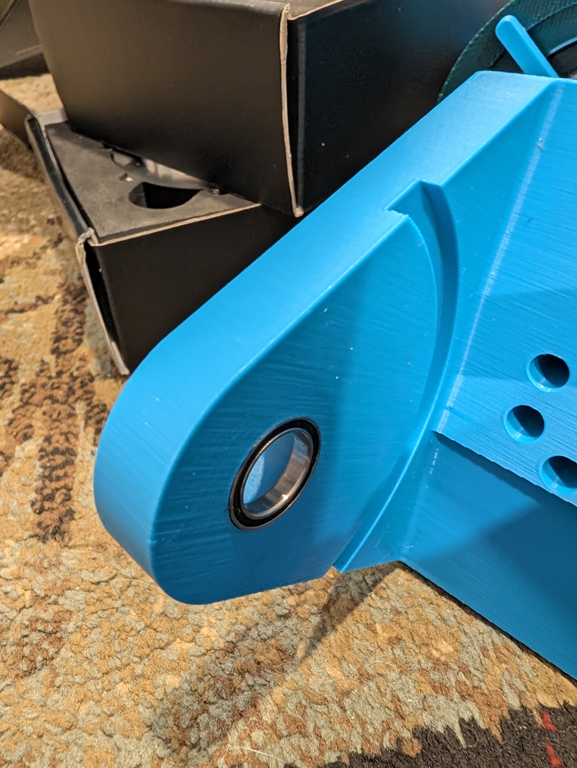
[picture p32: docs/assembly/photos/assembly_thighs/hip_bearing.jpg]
Hip Bearing


2. Insert `femur_22` into the bearing/hipxy.

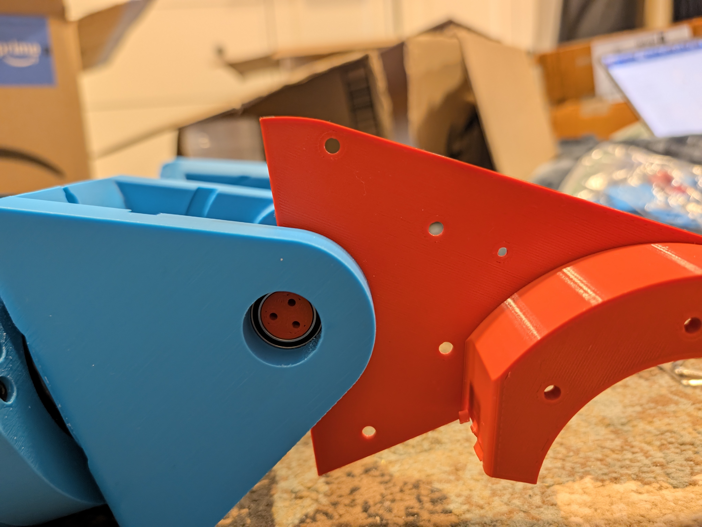
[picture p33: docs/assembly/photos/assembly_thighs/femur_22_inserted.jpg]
Femur 22 inserted


3. Using three M2.5 x 6 screws, attach femur_hat_small_1 to `femur_22` over the bearing to hold the piece in place.

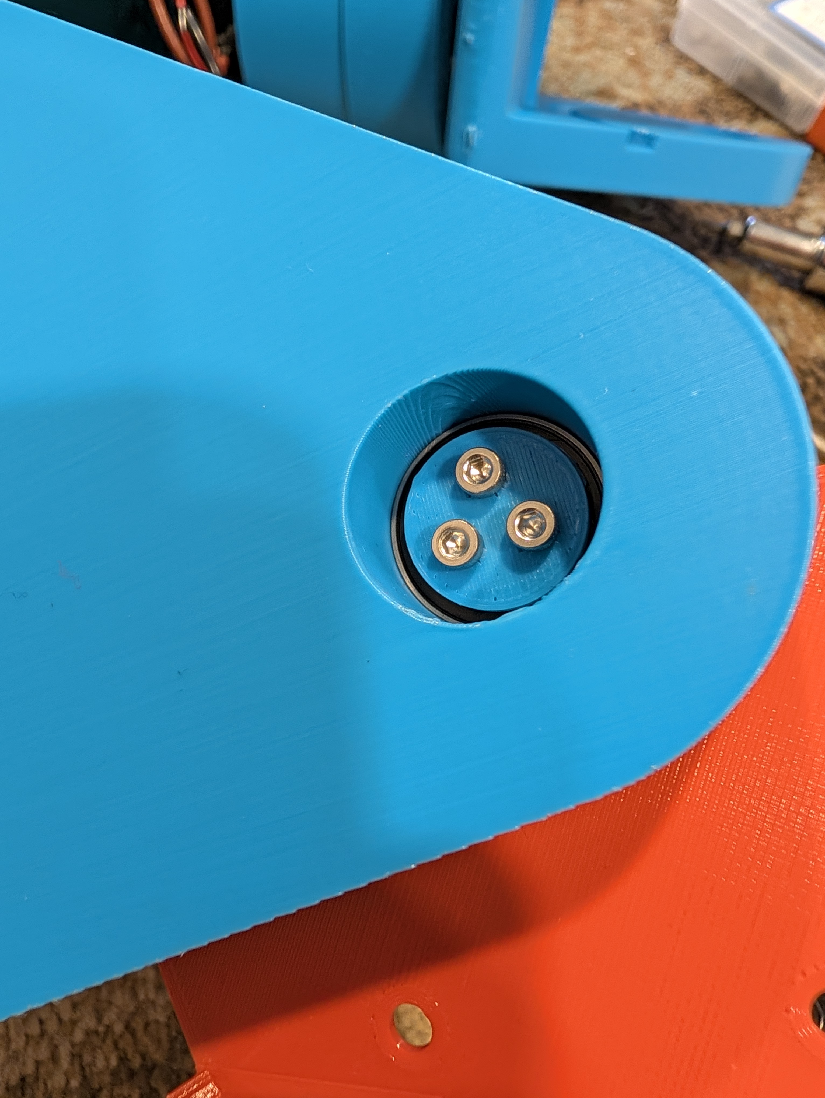
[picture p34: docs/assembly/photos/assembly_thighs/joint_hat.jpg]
Joint hat


4. The RobStride O3 motors will be inserted in a way where half of the motor should have screws on the back side and the other half of the backside shouldn't have any screws. Remove two of the screws beside one of the data/power ports and insert them into the blank spaces on the other side of the motor. You can do this for all of the RobStride O3 motors used in this subassembly.

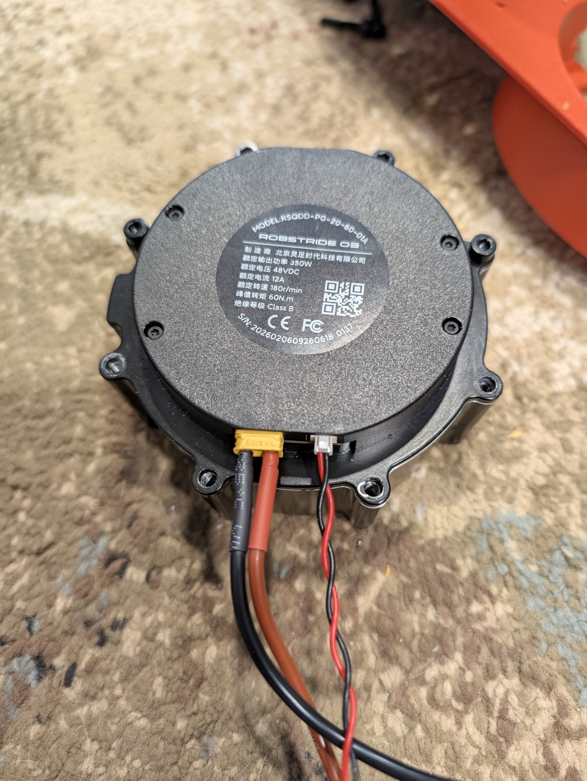
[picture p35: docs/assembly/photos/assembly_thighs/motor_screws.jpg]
Motor screw positions


5. Push RobStride O3 ID 3 (or 9 on the left leg) into `femur_12`. Align the holes that do not have screws so they are aligned with the openings in `femur_12`. Secure it with four M4 x 10 screws.

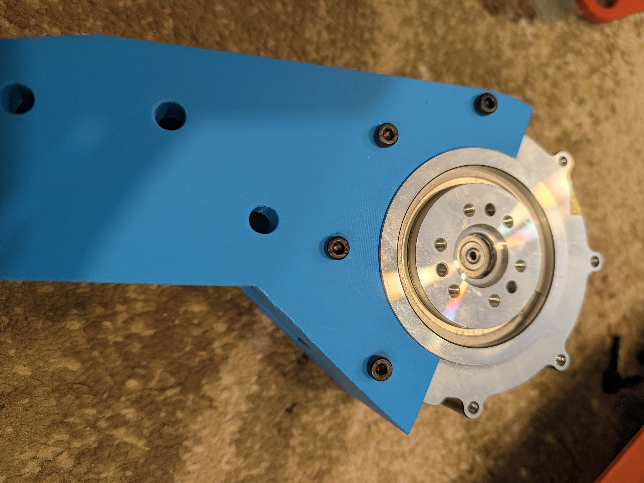
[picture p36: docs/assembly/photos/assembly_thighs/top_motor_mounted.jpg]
Mounted femur top motor


6. Attach `femur_12` to `hip_xy` using six M4 x 20 screws. `femur_22` should align with `femur_12` so that they fit flush together.

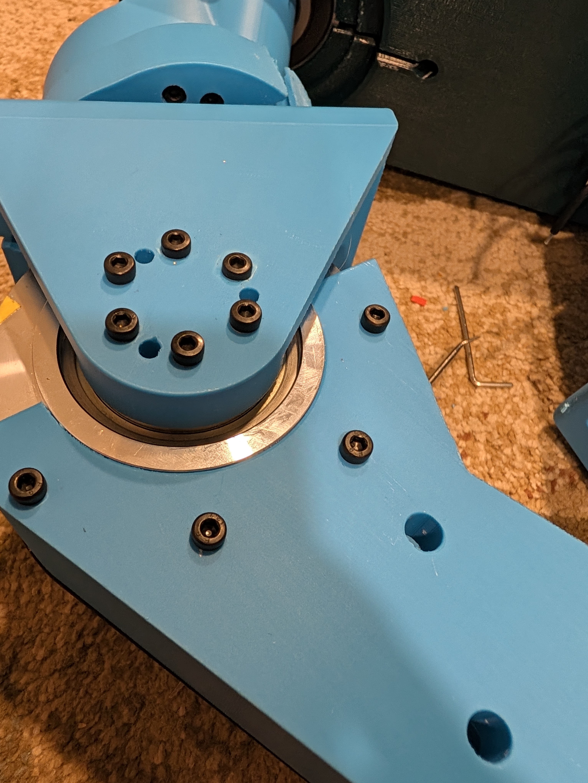
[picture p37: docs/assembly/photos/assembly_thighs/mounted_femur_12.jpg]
Mounted femur 12


7. Install and route the thigh sub-cable before final closing (`hardware/electronics/cabling/README.md`).

> Comment: Since I don't have the wiring diagram at this point, I'm holding off on routing wires. Do what you think is best here. - Paul Ruiz

8. Attach `femur_12` to `femur_22` using four M4 x 30 screws near the top motor and two M4 x 16 motors at the lower portion.

> Comment: I found the lower holes to be pretty loose. I added two M4 threaded heat inserts on both legs to secure it better. Just be careful here as the femurs were the pieces that took the longest to print, so you don't want to ruin them this early.

9. Insert the second RobStride O3 motor (ID 4 or 10) into the femur. If you didn't adjust the screws on the back earlier, now is the time to do that. Mount the motor into place using eight M4 x 10 screws (four on both sides).

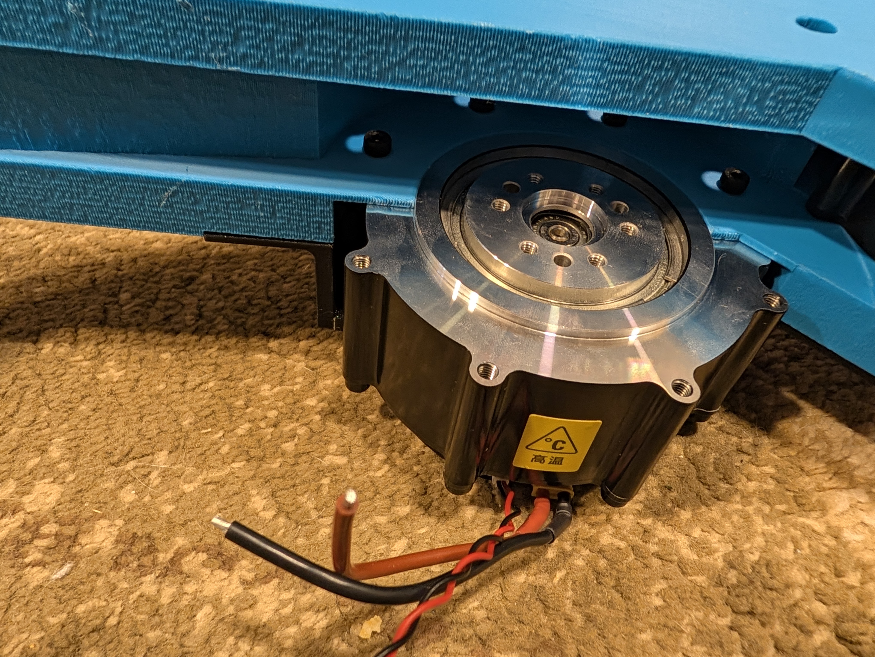
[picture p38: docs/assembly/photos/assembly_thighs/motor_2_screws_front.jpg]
Motor 2 screws front


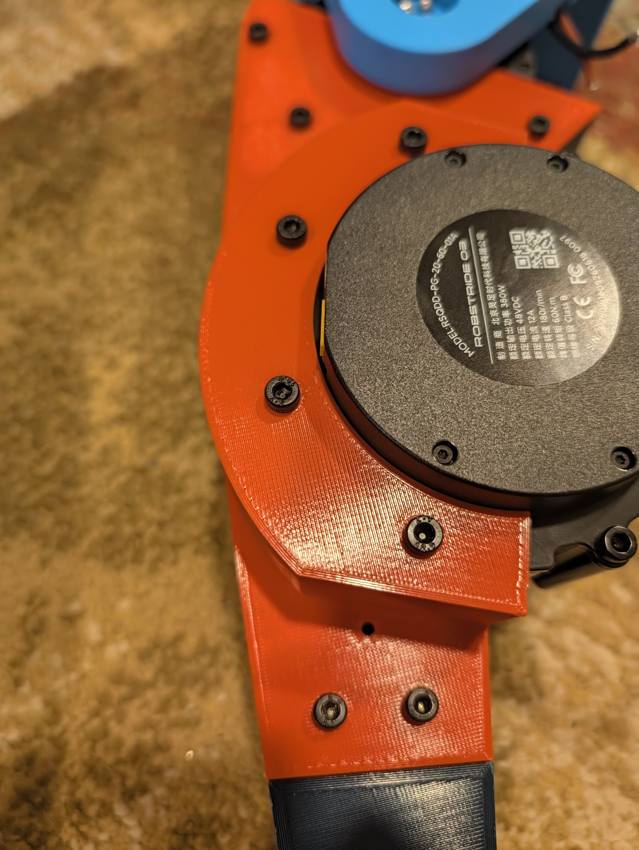
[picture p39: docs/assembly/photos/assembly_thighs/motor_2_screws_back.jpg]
Motor 2 screws back


> Comment: Do not lock thigh with permanent pins if you want it demountable.

Assembly at this point:

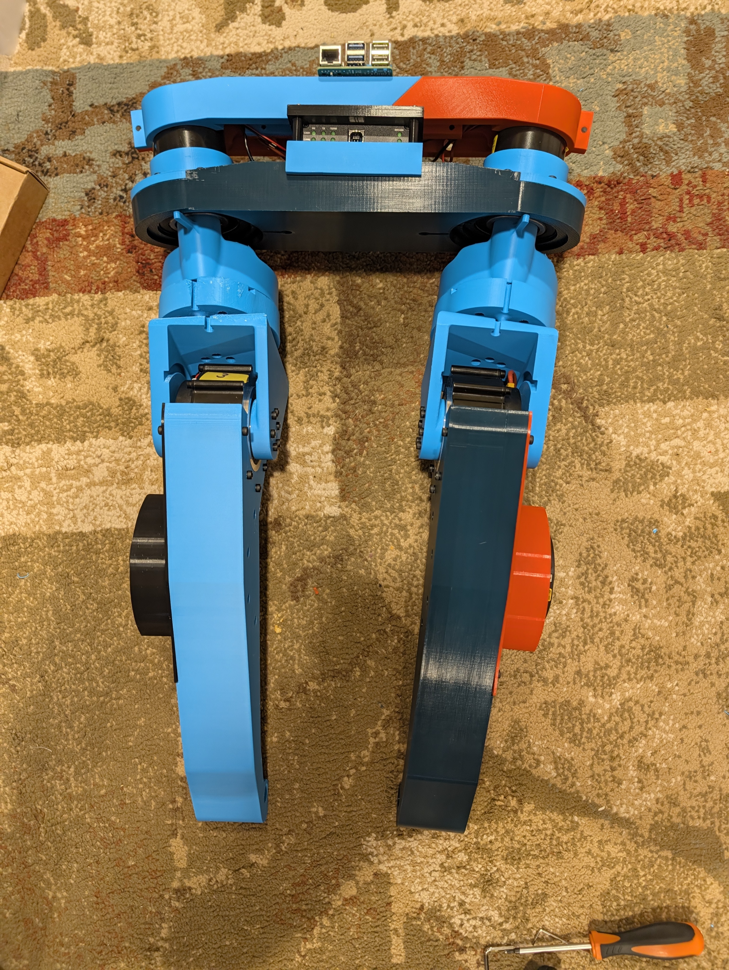
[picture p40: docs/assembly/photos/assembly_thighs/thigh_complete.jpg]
Thigh complete


## Foot and Ankle

Components:
| Category | Name | Specification | Qty / Subassembly | Qty / Robot |
|---|---|---|---:|---:|
| bearing | Bearing | 5x16x5 | 2 | 4 |
| fastener_screw | M2.5 screw | M2.5 x 8 cyl head | 9 | 18 |
| fastener_axis | Shoulder screw 07534-05X20 | 2 | 4 |
| fastener_axis | Shoulder screw 07534-05X40| 1 | 2 |
| fastener_nut | Nut M4 | M4 nut | 3 | 6 |
| joint_spherical | Spherical joint 27628-01-05 | 2 | 4

STL To Print:
| Name | Quantity |
|---|---:|
| left_leg/foot/bearing_spacer14_5_7_3.stl | 1 |
| left_leg/foot/bearing_spacer24_5_7_3.stl | 1 |
| left_leg/foot/bearing_spacer34_5_7_3.stl | 1 |
| left_leg/foot/bearing_spacer44_5_7_3.stl | 1 |
| left_leg/ankle/ujoint_spacer_12_ujoint.stl | 1 |
| left_leg/ankle/ujoint_spacer_22_ujoint.stl | 1 |
| left_leg/ankle/ujoint_ujoint.stl | 1 |
| left_leg/foot/foot_foot.stl | 1 |
| left_leg/foot/foot_hat_small.stl | 1 |
| right_leg/foot/bearing_spacer14_5_7_3.stl | 1 |
| right_leg/foot/bearing_spacer24_5_7_3.stl | 1 |
| right_leg/foot/bearing_spacer34_5_7_3.stl | 1 |
| right_leg/foot/bearing_spacer44_5_7_3.stl | 1 |
| right_leg/foot/foot_foot.stl | 1 |
| right_leg/foot/foot_hat_small.stl | 1 |
| right_leg/ankle/ujoint_spacer_12_ujoint.stl | 1 |
| right_leg/ankle/ujoint_spacer_22_ujoint.stl | 1 |
| right_leg/ankle/ujoint_ujoint.stl | 1 |

Assembly steps:

> Comment: You will follow these same steps for both feet.

1. Attach two spherical joints between the notches at the front of the foot and secure into place using two 5x20 shoulder screws. When inserting the shoulder screw, place a 5x6x3 spacer on both side of the spherical joints. Secure shoulder screw with an M4 nut.

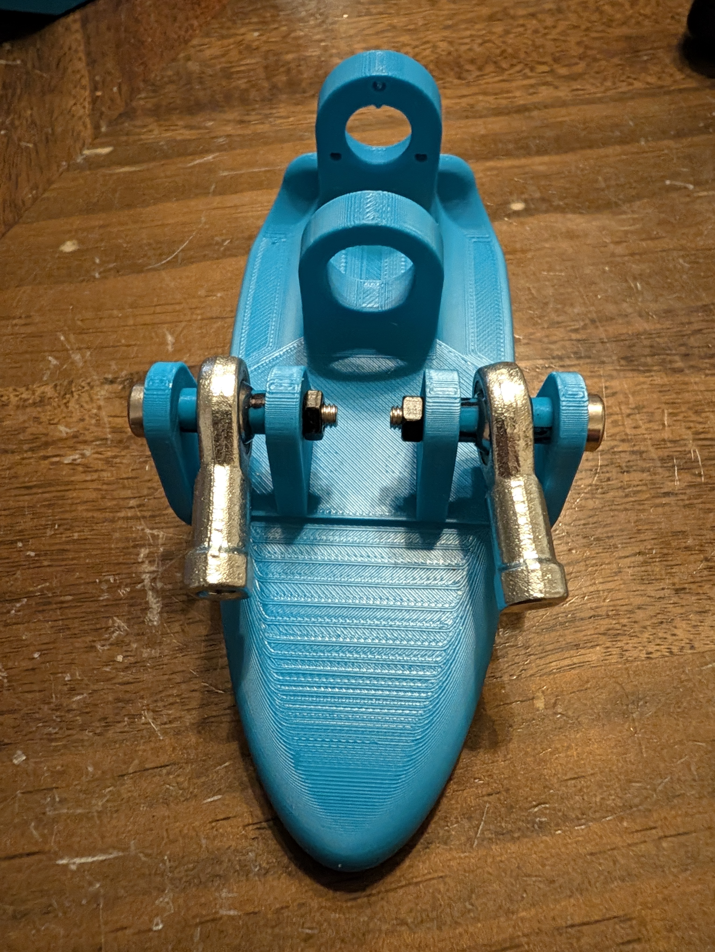
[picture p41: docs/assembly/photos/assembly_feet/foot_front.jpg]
Foot front spherical joints


2. Place two 5x16x5 bearings into the grooves at the back of the foot. Apply firm even pressure to seat them.

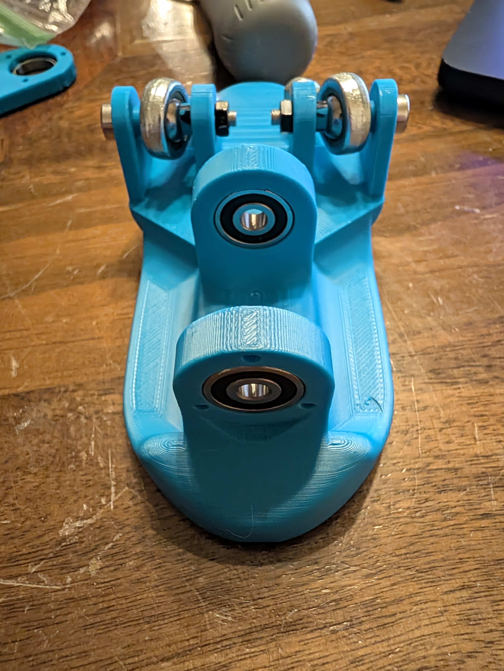
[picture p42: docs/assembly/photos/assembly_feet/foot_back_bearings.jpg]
Foot back bearings


3. Place the u-joint between the back bearings with a u-joint spacer on both sides of the ujoint. Secure into place using a 5x40 shoulder screw and M4 nut. Attach the foot_hat_small piece over the back bearing and secure in place using three M2.5x8 screws.

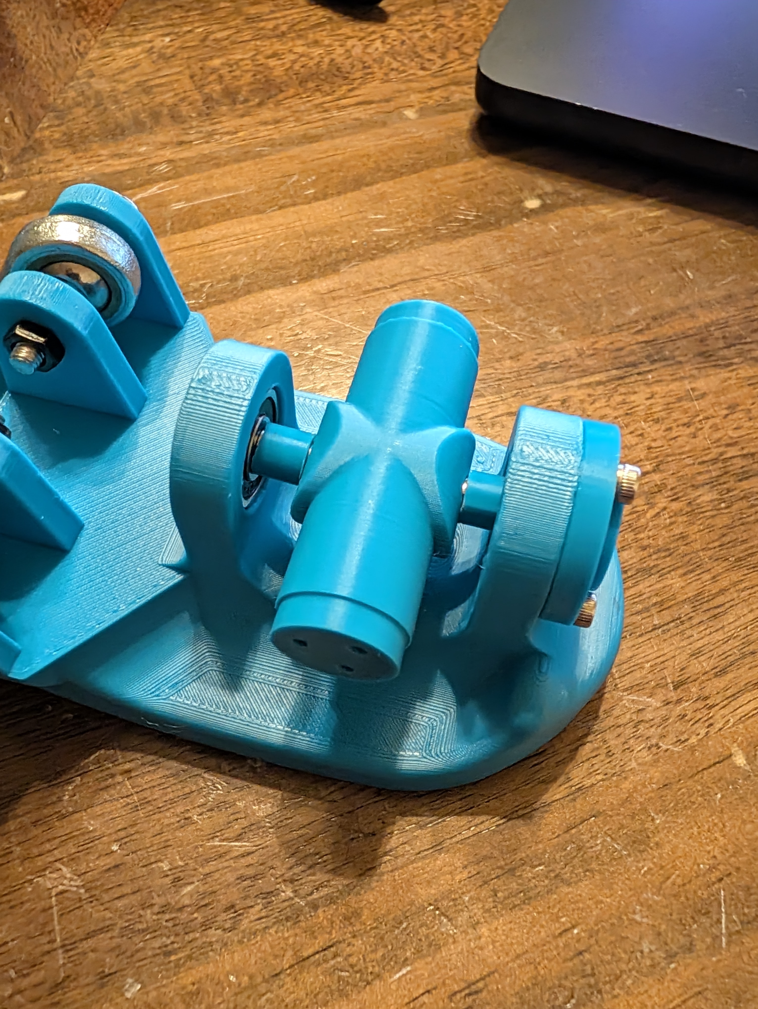
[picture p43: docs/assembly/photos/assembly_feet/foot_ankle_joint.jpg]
Foot ankle joint


4. Verify free ankle motion after tightening.

## knee_mechanism

Components:
| Category | Name | Specification | Qty / Subassembly | Qty / Robot |
|---|---|---|---:|---:|
| bearing | Bearing | 15x21x4 | 2 | 4 |
| fastener_screw | M3 screw | M3 x 18 cyl head | 3 | 6 |

STL To Print:
| Name | Quantity |
|---|---:|
| left_leg/knee_mechanism/femur_v2_knee_actuation_2.stl | 1 |
| left_leg/knee_mechanism/femur_v2_knee_rod12_sym_1.stl | 1 |
| left_leg/knee_mechanism/femur_v2_knee_rod22_sym_1.stl | 1 |
| right_leg/knee_mechanism/femur_v2_knee_actuation_1.stl | 1 |
| right_leg/knee_mechanism/femur_v2_knee_rod12_1.stl | 1 |
| right_leg/knee_mechanism/femur_v2_knee_rod22_1.stl | 1 |

Assembly steps:
1. Place a 15x21x4 bearing on either side of the knee actuator.

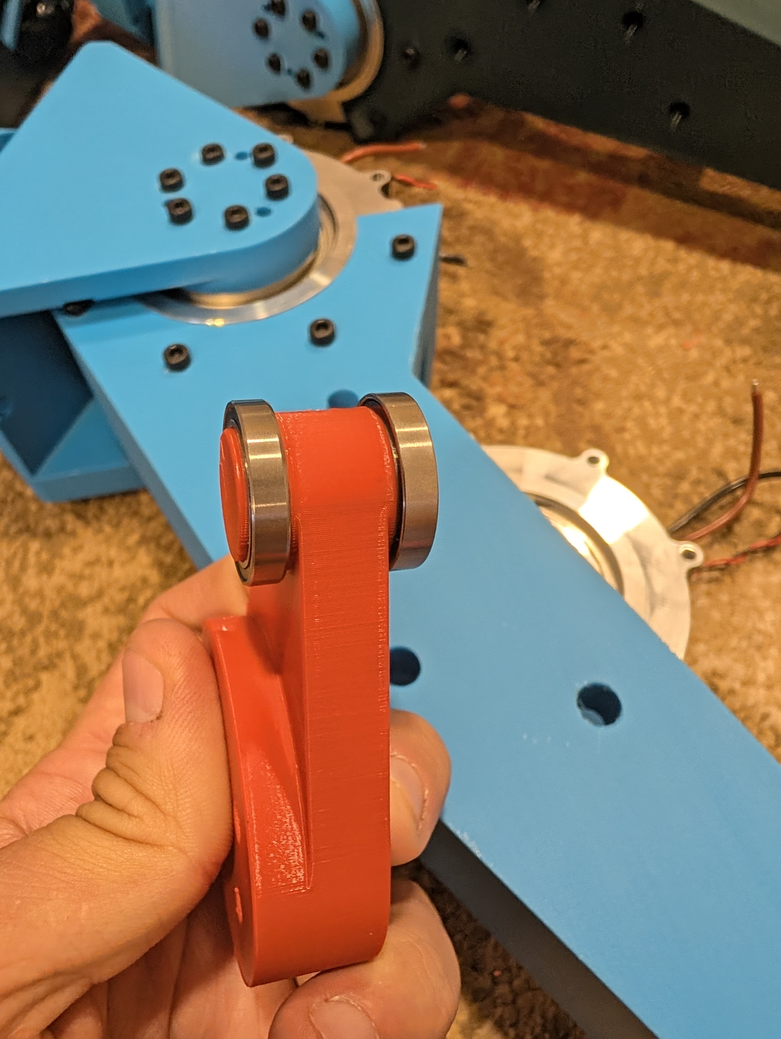
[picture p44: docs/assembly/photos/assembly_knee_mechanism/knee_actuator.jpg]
Knee actuator with bearings


2. Attach knee_rod12 and knee_rod22 to the knee actuator, then align and secure with three M3x18 screws. Confirm orientation as this mechanism will move the tibia from the femur and needs to align properly to not collide with other parts of the robot.

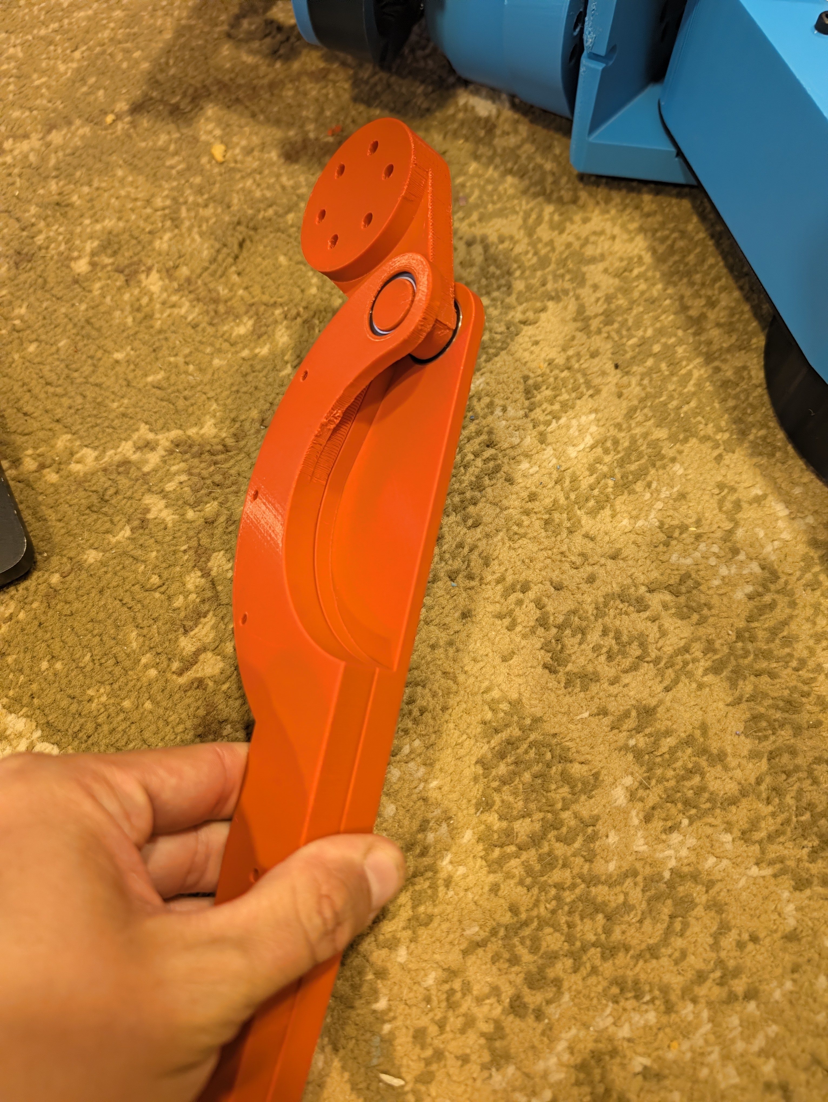
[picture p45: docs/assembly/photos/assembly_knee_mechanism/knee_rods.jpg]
Knee rods for subassembly


3. Set this subassembly aside, as it will be used at the end of the next step.

## Shin

Components:
| Category | Name | Specification | Qty / Subassembly | Qty / Robot |
|---|---|---|---:|---:|
| motor | RobStride O5 | actuator | 2 | 4 |
| bearing | Bearing | 15x21x4 | 2 | 4 |
| fastener_nut | Nut M3 | M3 nut | 1 | 2 |
| fastener_screw | M3 screw | M3 x 50 cyl head | 1 | 2 |
| fastener_screw | M4 screw | M4 x 18 cyl head | 4 | 8 |
| fastener_screw | M4 screw | M4 x 10 cyl head | 16 | 32 |
| fastener_screw | M2.5 screw | M2.5 x 8 cyl head | 9 | 18 |
| fastener_nut | Nut M4 | M4 nut | 4 | 8 |

STL To Print:
| Name | Quantity |
|---|---:|
| left_leg/shin/spacer12_5_9_4_5.stl | 1 |
| left_leg/shin/spacer22_5_9_4_5.stl | 1 |
| left_leg/shin/tibias2_hat_big.stl | 1 |
| left_leg/shin/tibias2_shin_spacer_2.stl | 1 |
| left_leg/shin/tibias2_tibias12_sym_4.stl | 1 |
| left_leg/shin/tibias2_tibias22_sym_4.stl | 1 |
| left_leg/ankle/ujoint_hat_small_12.stl | 1 |
| left_leg/ankle/ujoint_hat_small_22.stl | 1 |
| right_leg/shin/spacer12_5_9_4_5.stl | 1 |
| right_leg/shin/spacer22_5_9_4_5.stl | 1 |
| right_leg/shin/tibias2_hat_big.stl | 1 |
| right_leg/shin/tibias2_shin_spacer_2.stl | 1 |
| right_leg/shin/tibias2_tibias12.stl | 1 |
| right_leg/shin/tibias2_tibias22.stl | 1 |
| right_leg/ankle/ujoint_hat_small_12.stl | 1 |
| right_leg/ankle/ujoint_hat_small_22.stl | 1 |

Assembly steps:

> Comment: You will do these steps for each leg.

1. Insert two 15x21x4 bearings into the slots on the tibia and two pins at the top and bottom of the tibia.

> Comment: This is a very tight fit! I applied WD-40 and gently tapped with a hammer to insert the bearings, but on my first attempt I cracked both slots. You can repair using a soldering iron to melt the 3D printed parts back together, but that's not ideal. Slow and gentle is the best course of action here.

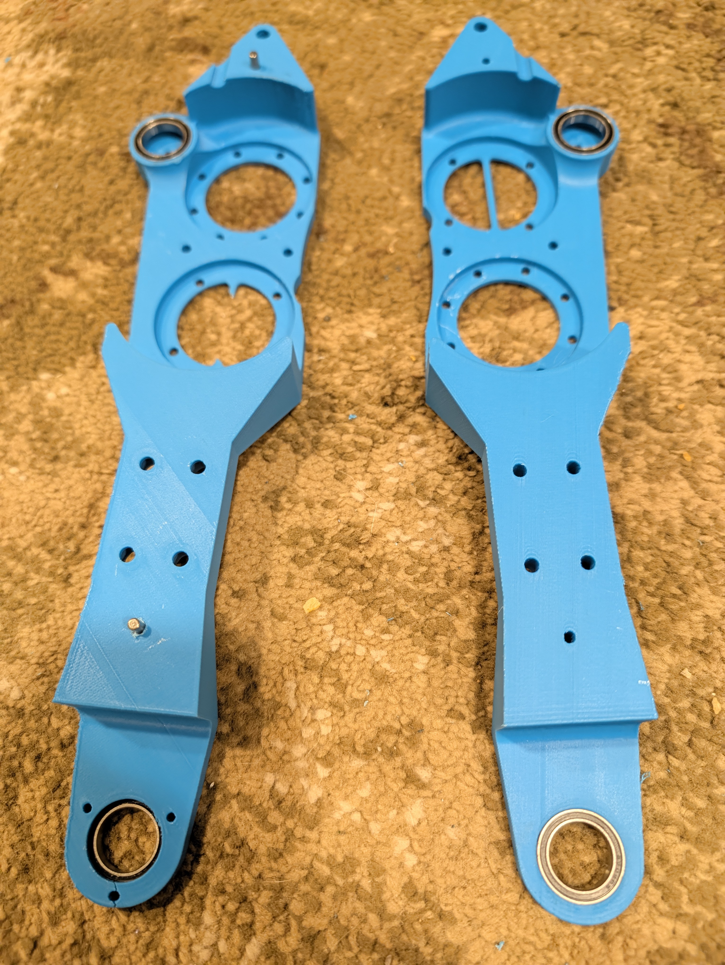
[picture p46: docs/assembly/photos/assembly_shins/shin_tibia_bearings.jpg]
Tibia with bearings and pins


2. Attach the RobStride o5 motors to the tibias. Align them so that the cables will come out of the *front* of the tibia (the side without the top bearing). Double check that the back openings will align with the other tibia half. Secure with eight M3x10 screws.

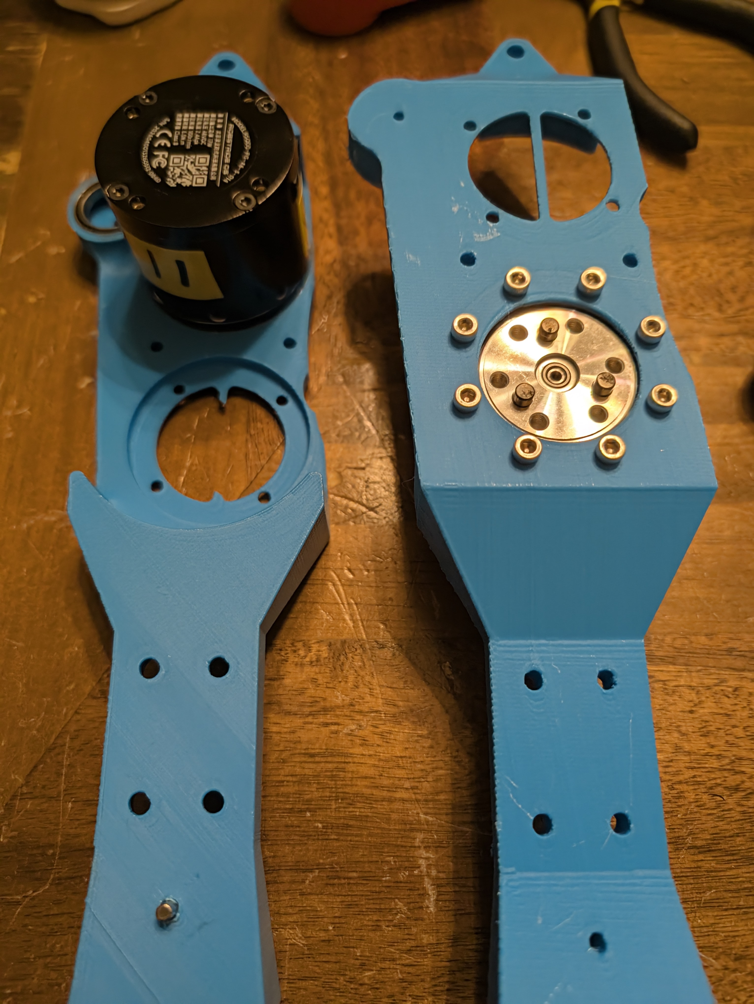
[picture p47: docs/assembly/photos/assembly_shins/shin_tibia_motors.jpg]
Tibia motors


3. Place one half of the shin onto the foot's u-joint. Confirm the directionality - the bearing at the top of the tibia should face the back of the foot. Secure the bearing on the ujoint using ujoint_hat_small and fasten with three M2.5x8 screws.

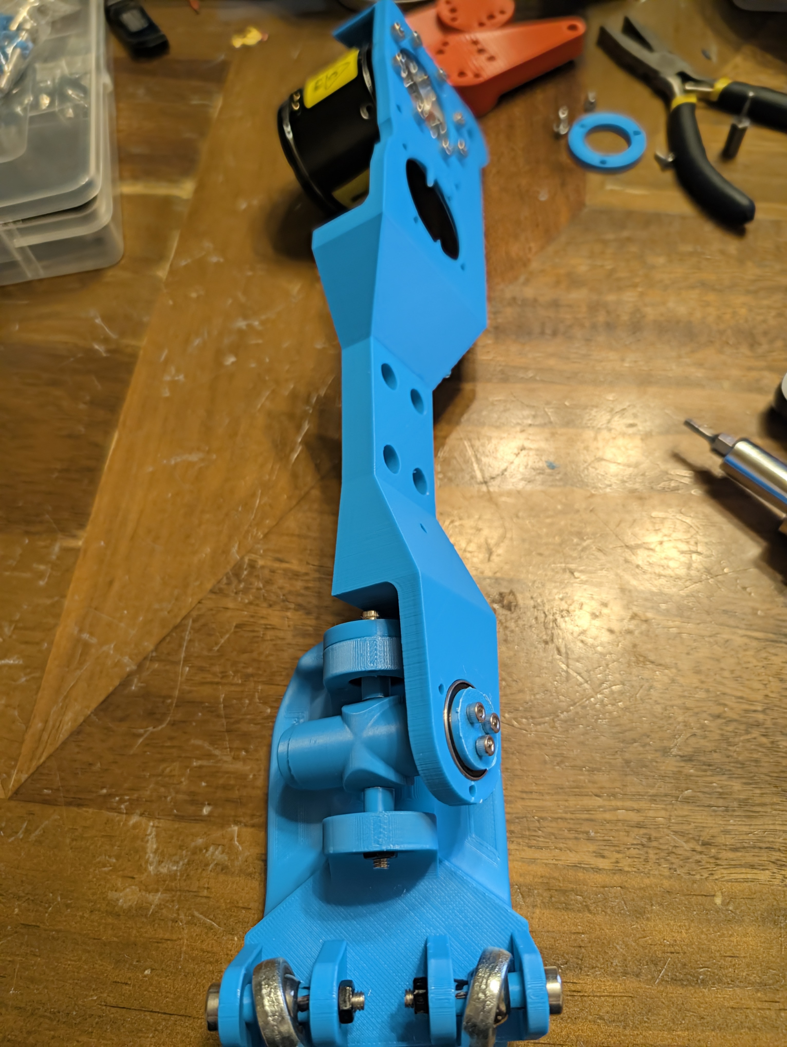
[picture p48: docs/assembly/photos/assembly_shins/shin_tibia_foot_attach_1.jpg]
Tibia motors


4. Place the appropriate knee mechanism into the tibia top bearing.

> Comment: Confirm orientation (shown in the next photo) as the part of the knee actuator that extends out should face the same direction as the actuating part of the top RobStride o5 motor in the tibia.

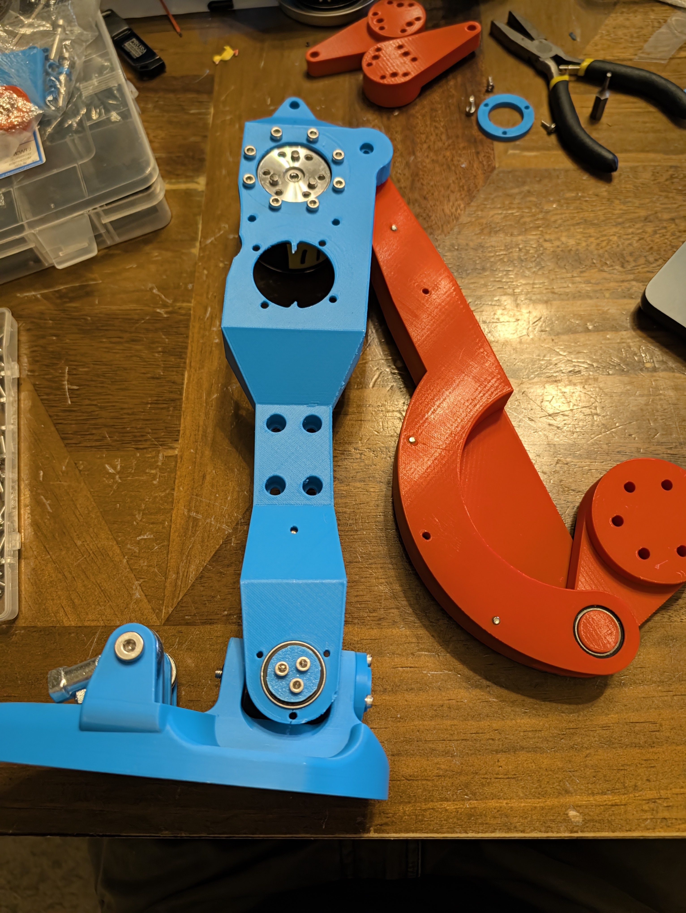
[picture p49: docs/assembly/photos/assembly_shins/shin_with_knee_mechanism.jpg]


5. Place the second half of the tibia onto the first. This will be loose to start, so hold it tight as you secure it with four M4x18 screws above the ankle and secure with four M4 nuts. Secure the back side of the motors with four M3x10 screws, then use six M2.5 x 8 to add the u-joint hat and the tibia hat.

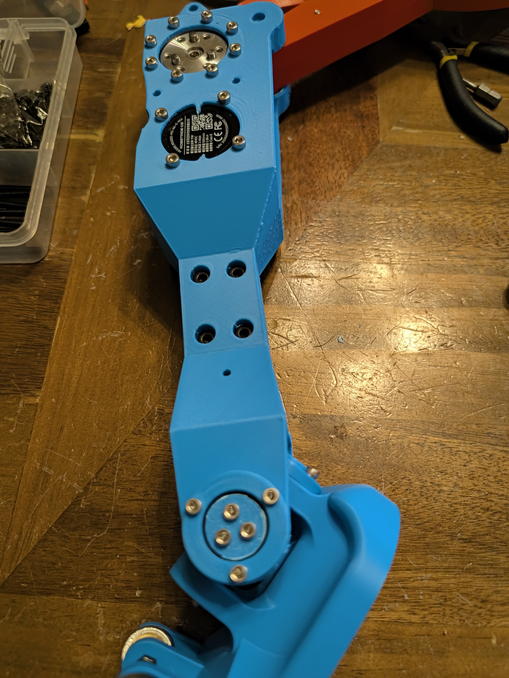
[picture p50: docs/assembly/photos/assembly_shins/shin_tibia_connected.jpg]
Tibia halves connected


6. Place an M3x50 screw through the openings where the tibia connects to the knee mechanism. Secure with an M3 nut.

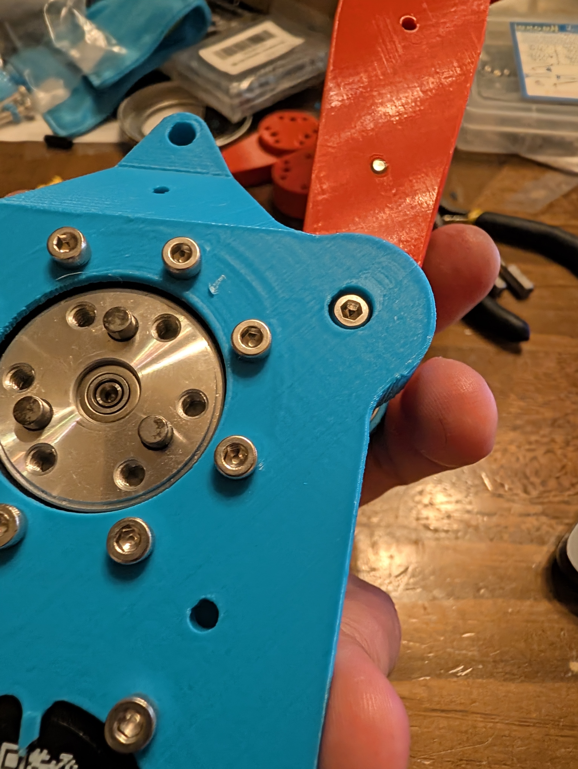
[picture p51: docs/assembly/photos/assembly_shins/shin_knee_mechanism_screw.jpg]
Tibia knee mechanism screw location


7. Slide the tibia spacer between the two motors and secure with four M4 x 10 screws.

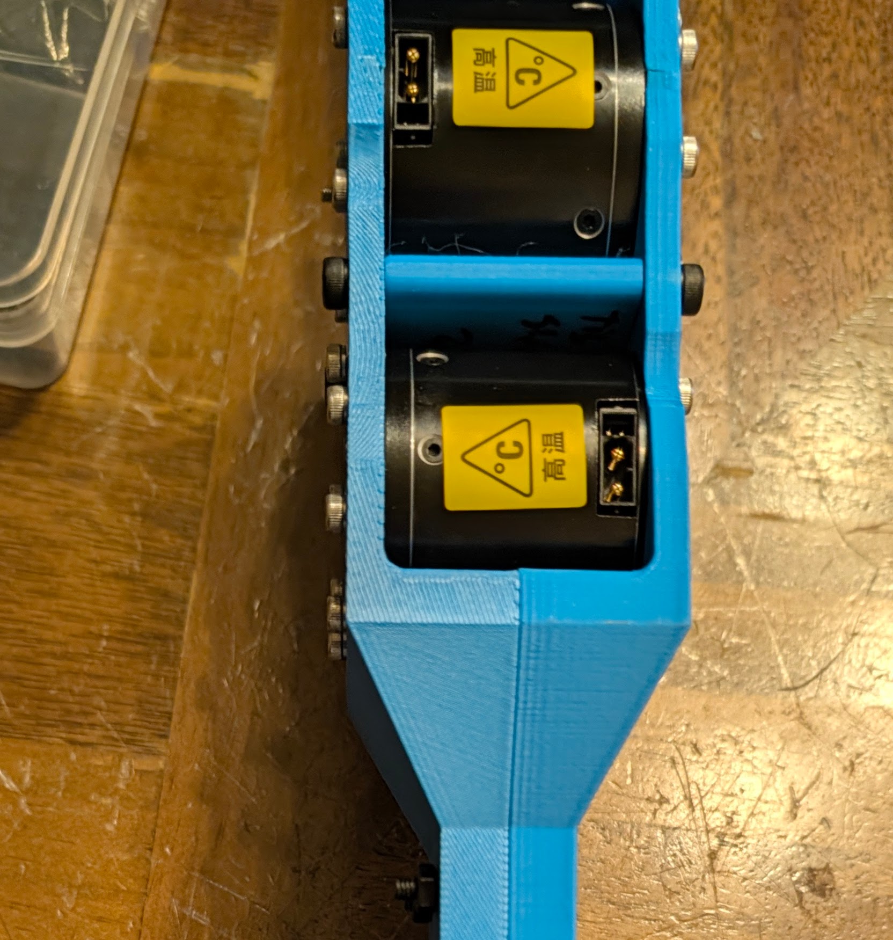
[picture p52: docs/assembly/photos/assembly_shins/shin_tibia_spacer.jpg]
Tibia spacer


## Ankle Mechanism

Components:
| Category | Name | Specification | Qty / Subassembly | Qty / Robot |
|---|---|---|---:|---:|
| fastener_screw | M5 screw | M5 x 15 cyl head | 4 | 8 |
| joint_spherical | Spherical joint 27628-01-05 | Norelem | 4 | 8 |
| fastener_axis | Shoulder screw 07534-05X20 | ISO7379, D1=5, L1=20, B=8, M4, steel 12.9 | 4 | 8 |
| bearing | Bearing | 5x16x5 | 2 | 4 |

STL To Print:
| Name | Quantity |
|---|---:|
| left_leg/ankle_mechanism/bearing_spacer14_5_7_3.stl | 1 |
| left_leg/ankle_mechanism/bearing_spacer24_5_7_3.stl | 1 |
| left_leg/ankle_mechanism/bearing_spacer34_5_7_3.stl | 1 |
| left_leg/ankle_mechanism/bearing_spacer44_5_7_3.stl | 1 |
| left_leg/ankle_mechanism/tibias2_rod_long.stl | 1 |
| left_leg/ankle_mechanism/tibias2_rod_small.stl | 1 |
| left_leg/ankle_mechanism/tibias_actuation_ankle_12.stl | 1 |
| left_leg/ankle_mechanism/tibias_actuation_ankle_22.stl | 1 |
| right_leg/ankle_mechanism/bearing_spacer14_5_7_3.stl | 1 |
| right_leg/ankle_mechanism/bearing_spacer24_5_7_3.stl | 1 |
| right_leg/ankle_mechanism/bearing_spacer34_5_7_3.stl | 1 |
| right_leg/ankle_mechanism/bearing_spacer44_5_7_3.stl | 1 |
| right_leg/ankle_mechanism/tibias2_rod_long.stl | 1 |
| right_leg/ankle_mechanism/tibias2_rod_small.stl | 1 |
| right_leg/ankle_mechanism/tibias_actuation_ankle_12.stl | 1 |
| right_leg/ankle_mechanism/tibias_actuation_ankle_22.stl | 1 |

Assembly steps:

1. Install the spherical joints on two ankle actuators using a 5x7x3 spacer, a 5x20 shoulder screw, and an M4 nut.

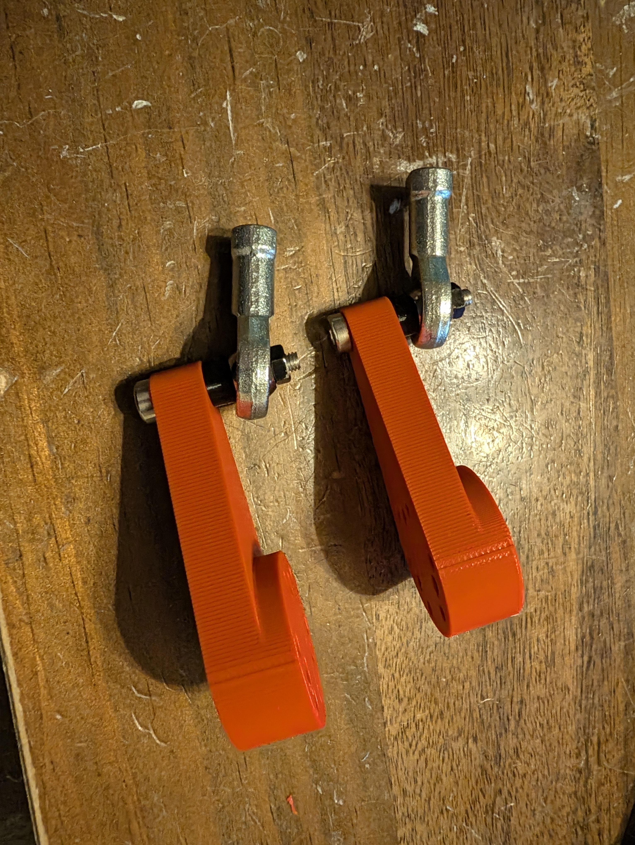
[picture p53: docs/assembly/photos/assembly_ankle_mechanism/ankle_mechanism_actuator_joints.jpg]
Joints on ankle actuators


2. Attach the ankle actuators to the Robstride o5 motors using 6 M4x20 screws per motor.

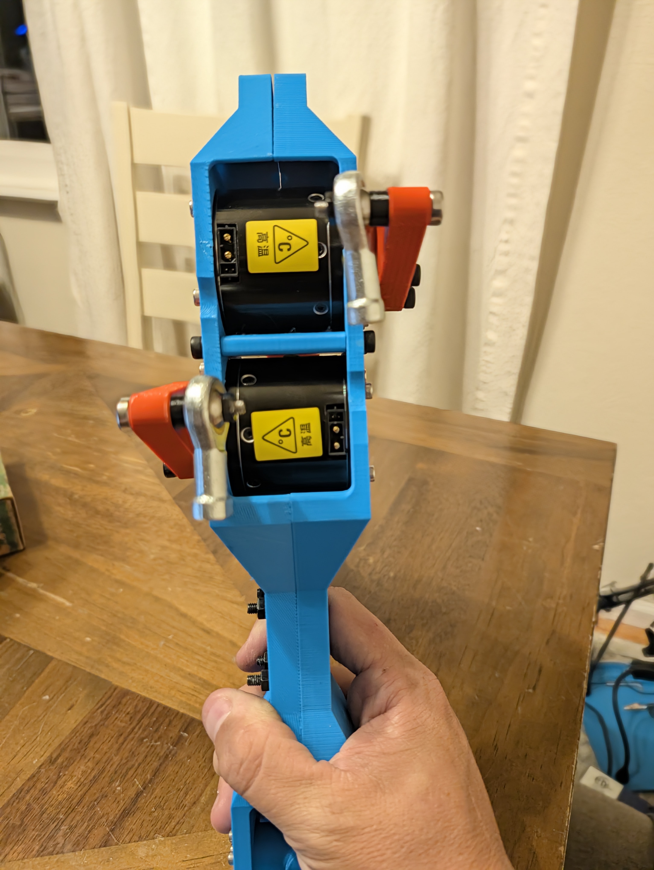
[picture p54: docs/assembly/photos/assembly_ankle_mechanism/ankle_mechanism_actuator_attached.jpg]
Attached ankle actuator


3. Attach the short and long tibia rods to the corresponding spherical joints using 2 M5x15 screws and a 5x7x3 spacer. Verify that the lower leg can move freely.

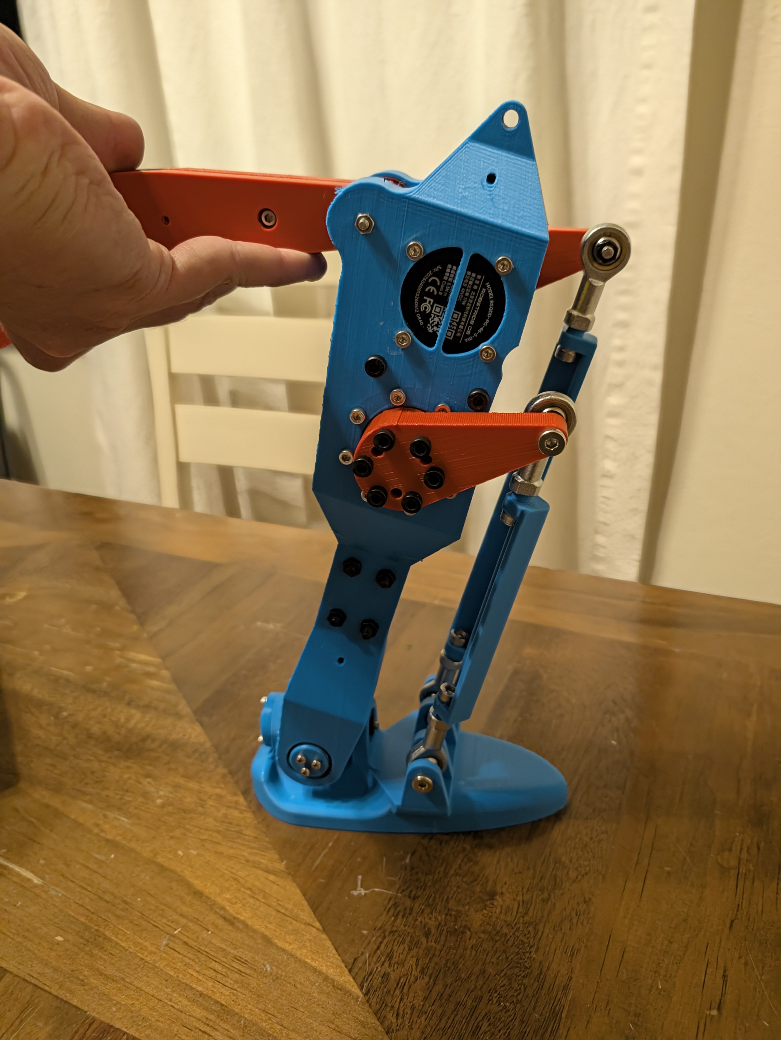
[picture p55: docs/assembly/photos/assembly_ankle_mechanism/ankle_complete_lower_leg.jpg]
Lower leg side


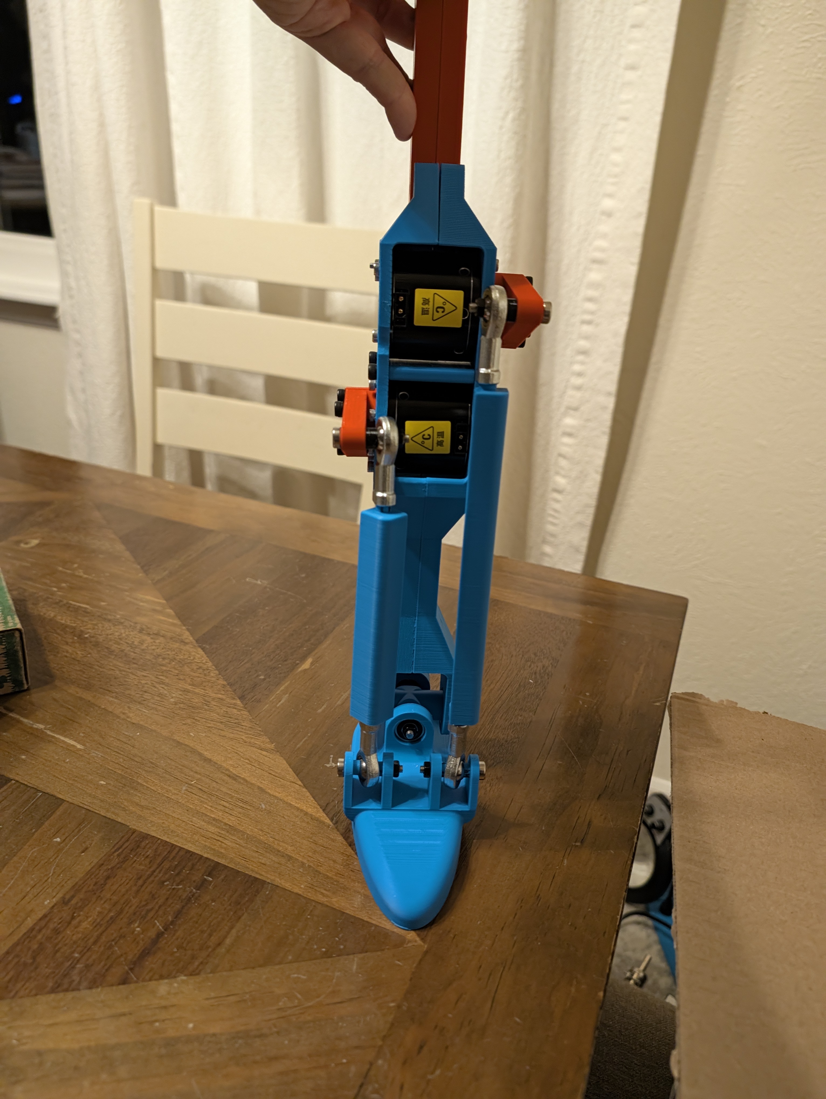
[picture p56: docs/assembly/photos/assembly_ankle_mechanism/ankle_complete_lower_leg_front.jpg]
Lower leg front


## Final Assembly

| Category | Name | Qty / Subassembly | Qty / Robot |
|---|---|---:|---:|
| bearing | 5x16x5 bearing | 2 | 4 |
| fastener_axis | Shoulder screw 07534-05X40| 1 | 2 |
| fastener_screw | M2.5 x 8 cyl head | 3 | 6 |
| fastener_screw | M4 x 20 cyl head | 6 | 12 |
| fastener_nut | M4 nut | 1 | 2 |

STL To Print:
| Name | Quantity |
|---|---:|
| left_leg/ankle_mechanism/bearing_spacer34_5_7_3.stl | 1 |
| left_leg/ankle_mechanism/bearing_spacer44_5_7_3.stl | 1 |
| left_leg/thigh/femur_v2_hat_femur_2.stl | 1 |
| right_leg/ankle_mechanism/bearing_spacer34_5_7_3.stl | 1 |
| right_leg/ankle_mechanism/bearing_spacer44_5_7_3.stl | 1 |
| right_leg/thigh/femur_v2_hat_femur_2.stl | 1 |

Assembly steps:

1. Place two 5x16x5 bearings into the bottom of the femur. Place the bearings on the outside edge of the lower femur and push them in to the inner edge.

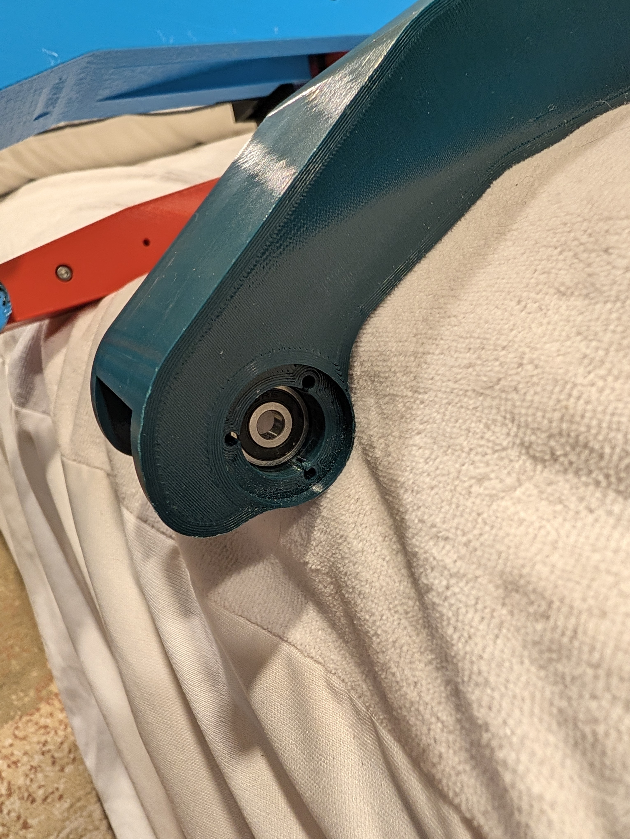
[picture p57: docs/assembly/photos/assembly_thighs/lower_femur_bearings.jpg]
Lower femur bearings


2. Attach the lower leg to the femur using a 5x40 shoulder screw, two 5xz7x3 spacers, and an M4 nut. Secure it with three M2.5x8 screws.

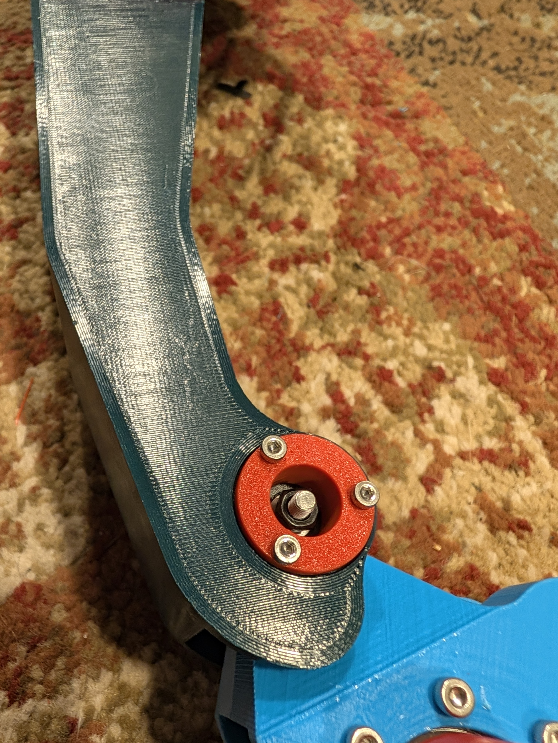
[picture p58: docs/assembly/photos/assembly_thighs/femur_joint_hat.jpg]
Femur joint hat


3. Attach the knee mechanism to motor 4/10 using 6 M4x20 screws.

> Comment: Attach the furthest away hole first, then spin the motor into position, otherwise the femur will block the screw entry point without the ability to rotate the last hole out for tightening.

Femur to knee mechanism screw offset

At this point your robot should be mechanically assembled. For next steps, if you haven't done the electrical wiring during the process, do that now, otherwise move on to the LeRobot Humanoid Runtime.

Femur joint hat

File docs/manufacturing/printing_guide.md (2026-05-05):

# Printing Guide

Generic recommendation:
- Printer baseline: `Bambu Lab H2D`
- Material baseline: `PLA+` for all robot printed parts
- Infill: `30%`
- Wall count: `4`
- Layer height: `0.15 mm`
- Infill pattern: `gyroid`
- Nozzle: `0.2 mm`

Anti-delamination and orientation rule:
- For structural parts, orient prints so layer lines do not take the main tensile load.
- If orientation is ambiguous, check Onshape assembly orientation first, then compare with mounted reference photos in `docs/assembly/photos/`.
- Orientation reference photos to inspect line direction and final part pose:
  - `docs/assembly/photos/thigh_detail.jpg`
  - `docs/assembly/photos/knee_detail.jpg`
  - `docs/assembly/photos/knee_mechanism_view_1.jpg`
  - `docs/assembly/photos/knee_mechanism_view_2.jpg`
  - `docs/assembly/photos/knee_mechanism_view_3.jpg`

H2D reference project files (critical parts):
- `docs/manufacturing/h2d_profiles/shin_tibias_example.3mf` + `docs/manufacturing/h2d_profiles/shin_tibias_print_example.png`
- `docs/manufacturing/h2d_profiles/thigh_femur_example.3mf` + `docs/manufacturing/h2d_profiles/thigh_print_example.png`
- `docs/manufacturing/h2d_profiles/hip_example.3mf` + `docs/manufacturing/h2d_profiles/hip_print_example.png`
- Other parts are more straightforward and usually do not require dedicated `.3mf` guidance.
- See `docs/manufacturing/h2d_profiles/README.md` for quick mapping.

Intentional documentation scope:
- Detailed slicing/orientation help is provided only for critical structural parts (`shin`, `thigh`, `hip`).
- For other parts, there is usually one obvious safe orientation; if not, verify with Onshape and mounted assembly photos.

## torso

| stl | quantity |
|---|---:|
| torso/torso_can_holder.stl | 1 |
| torso/torso_imu_holder.stl | 1 |
| torso/torso_torso13.stl | 1 |
| torso/torso_torso23.stl | 1 |
| torso/torso_torso33.stl | 1 |
| torso/torso_uper_torso_22.stl | 1 |
| torso/torso_upper_torso_12.stl | 1 |

## hipz

| stl | quantity |
|---|---:|
| left_leg/hipz/hip_z_hipz12_sym.stl | 1 |
| left_leg/hipz/hip_z_hipz22_sym.stl | 1 |
| right_leg/hipz/hip_z_hipz12.stl | 1 |
| right_leg/hipz/hip_z_hipz22.stl | 1 |

Special recommendation: use `100%` infill for this subassembly.
Reference project:
- `docs/manufacturing/h2d_profiles/hip_example.3mf`
- `docs/manufacturing/h2d_profiles/hip_print_example.png`

## hipx

| stl | quantity |
|---|---:|
| left_leg/hipx/hipx_2_hipxy_sym.stl | 1 |
| right_leg/hipx/hipx_2_hipxy.stl | 1 |

Special recommendation: use `100%` infill for this subassembly.

## thigh

| stl | quantity |
|---|---:|
| left_leg/thigh/femur_v2_femur_12_sym_1.stl | 1 |
| left_leg/thigh/femur_v2_femur_22_sym_1.stl | 1 |
| left_leg/thigh/femur_v2_hat_femur_2.stl | 1 |
| right_leg/thigh/femur_v2_femur_12_1.stl | 1 |
| right_leg/thigh/femur_v2_femur_22_1.stl | 1 |
| right_leg/thigh/femur_v2_hat_femur_2.stl | 1 |

Special recommendation: for the large thigh part, print it on its side (not on its front face).
Reference project:
- `docs/manufacturing/h2d_profiles/thigh_femur_example.3mf`
- `docs/manufacturing/h2d_profiles/thigh_print_example.png`

## knee_mechanism

| stl | quantity |
|---|---:|
| left_leg/knee_mechanism/femur_v2_knee_actuation_2.stl | 1 |
| left_leg/knee_mechanism/femur_v2_knee_rod12_sym_1.stl | 1 |
| left_leg/knee_mechanism/femur_v2_knee_rod22_sym_1.stl | 1 |
| right_leg/knee_mechanism/femur_v2_knee_actuation_1.stl | 1 |
| right_leg/knee_mechanism/femur_v2_knee_rod12_1.stl | 1 |
| right_leg/knee_mechanism/femur_v2_knee_rod22_1.stl | 1 |

## shin

| stl | quantity |
|---|---:|
| left_leg/shin/spacer12_5_9_4_5.stl | 1 |
| left_leg/shin/spacer22_5_9_4_5.stl | 1 |
| left_leg/shin/tibias2_hat_big.stl | 1 |
| left_leg/shin/tibias2_shin_spacer_2.stl | 1 |
| left_leg/shin/tibias2_tibias12_sym_4.stl | 1 |
| left_leg/shin/tibias2_tibias22_sym_4.stl | 1 |
| right_leg/shin/spacer12_5_9_4_5.stl | 1 |
| right_leg/shin/spacer22_5_9_4_5.stl | 1 |
| right_leg/shin/tibias2_hat_big.stl | 1 |
| right_leg/shin/tibias2_shin_spacer_2.stl | 1 |
| right_leg/shin/tibias2_tibias12.stl | 1 |
| right_leg/shin/tibias2_tibias22.stl | 1 |

Reference project:
- `docs/manufacturing/h2d_profiles/shin_tibias_example.3mf`
- `docs/manufacturing/h2d_profiles/shin_tibias_print_example.png`

## ankle_mechanism

| stl | quantity |
|---|---:|
| left_leg/ankle_mechanism/bearing_spacer14_5_7_3.stl | 1 |
| left_leg/ankle_mechanism/bearing_spacer24_5_7_3.stl | 1 |
| left_leg/ankle_mechanism/bearing_spacer34_5_7_3.stl | 1 |
| left_leg/ankle_mechanism/bearing_spacer44_5_7_3.stl | 1 |
| left_leg/ankle_mechanism/tibias2_rod_long.stl | 1 |
| left_leg/ankle_mechanism/tibias2_rod_small.stl | 1 |
| left_leg/ankle_mechanism/tibias_actuation_ankle_12.stl | 1 |
| left_leg/ankle_mechanism/tibias_actuation_ankle_22.stl | 1 |
| right_leg/ankle_mechanism/bearing_spacer14_5_7_3.stl | 1 |
| right_leg/ankle_mechanism/bearing_spacer24_5_7_3.stl | 1 |
| right_leg/ankle_mechanism/bearing_spacer34_5_7_3.stl | 1 |
| right_leg/ankle_mechanism/bearing_spacer44_5_7_3.stl | 1 |
| right_leg/ankle_mechanism/tibias2_rod_long.stl | 1 |
| right_leg/ankle_mechanism/tibias2_rod_small.stl | 1 |
| right_leg/ankle_mechanism/tibias_actuation_ankle_12.stl | 1 |
| right_leg/ankle_mechanism/tibias_actuation_ankle_22.stl | 1 |

## ankle

| stl | quantity |
|---|---:|
| left_leg/ankle/ujoint_hat_small_12.stl | 1 |
| left_leg/ankle/ujoint_hat_small_22.stl | 1 |
| left_leg/ankle/ujoint_spacer_12_ujoint.stl | 1 |
| left_leg/ankle/ujoint_spacer_22_ujoint.stl | 1 |
| left_leg/ankle/ujoint_ujoint.stl | 1 |
| right_leg/ankle/ujoint_hat_small_12.stl | 1 |
| right_leg/ankle/ujoint_hat_small_22.stl | 1 |
| right_leg/ankle/ujoint_spacer_12_ujoint.stl | 1 |
| right_leg/ankle/ujoint_spacer_22_ujoint.stl | 1 |
| right_leg/ankle/ujoint_ujoint.stl | 1 |

## foot

| stl | quantity |
|---|---:|
| left_leg/foot/bearing_spacer14_5_7_3.stl | 1 |
| left_leg/foot/bearing_spacer24_5_7_3.stl | 1 |
| left_leg/foot/bearing_spacer34_5_7_3.stl | 1 |
| left_leg/foot/bearing_spacer44_5_7_3.stl | 1 |
| left_leg/foot/foot_foot.stl | 1 |
| left_leg/foot/foot_hat_small.stl | 1 |
| right_leg/foot/bearing_spacer14_5_7_3.stl | 1 |
| right_leg/foot/bearing_spacer24_5_7_3.stl | 1 |
| right_leg/foot/bearing_spacer34_5_7_3.stl | 1 |
| right_leg/foot/bearing_spacer44_5_7_3.stl | 1 |
| right_leg/foot/foot_foot.stl | 1 |
| right_leg/foot/foot_hat_small.stl | 1 |

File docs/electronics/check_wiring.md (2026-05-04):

# Wiring Check Procedure

Run this before first power-on.

## 1. Visual and continuity checks

- Confirm every connector orientation.
- Match each physical connector against `hardware/electronics/connectors.md` and `hardware/electronics/connectors_photos/`.
- Confirm no exposed conductor can short to frame.
- Continuity-check power and ground path end-to-end.
- Verify there is no short between main power and ground.
- Apply the leg cabling legend and diagrams from `hardware/electronics/cabling/README.md` (red = power, green = CAN, blue = CAN + power).
- Use the same leg cabling pattern on both left and right legs.
- Shin sub-cable, thigh sub-cable, and hip pass-through sub-cable are all shown there.

## 2. Signal checks

- Confirm bus lines are not swapped.
- Confirm encoder and sensor pin polarity.
- Confirm shield/ground policy is consistent.

## 3. Pre-power checklist

- Bench supply current limit set to `2 A` for first logic-only bring-up.
- Emergency power cutoff reachable.
- Motor power path still disconnected for logic-only test.

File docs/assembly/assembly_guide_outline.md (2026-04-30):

# Assembly Guide Outline

## Build Sequence
1. Configure all motors before assembly (see `docs/electronics/motor_commissioning.md`).
2. Print all STL parts (`docs/manufacturing/printing_guide.md`).
3. Build torso first.
4. Build upper leg modules in this strict order (same for left and right): `hipx -> hipy (hipz in repo naming) -> thigh`.
5. In parallel, build lower leg modules in this strict order (same for left and right): `foot -> ankle -> knee_mechanism -> shin -> ankle_mechanism`.
6. Assemble upper leg with lower leg for each side.
7. Integrate both legs with torso, then complete wiring checks and first power-on (`docs/electronics/check_wiring.md`, `docs/electronics/first_power_on.md`).

## Build Paradigm
- Default approach: screws are threaded directly into plastic (no insert) for most plastic threads.
- Exception: shin uses M3 threaded inserts (`4 per shin`, `8 total`), this area is structural.
- Insert bearings first in each subassembly (press or gentle hammer).
- Place motor goupille/pin during the same phase as bearing insertion.
- For subassembly goupilles: place them during assembly except on `thigh` to keep it demountable.
- Knee and ankle each keep one interface slightly loose, but still movable.
- Some fits are intentionally tight; if needed, gently ream/drill to final diameter with a metal drill bit at low speed.
- Applied reference torque: about `5 Nm` for screws into non-structural plastic.
- For motor threaded holes and structural insert areas, use higher torque appropriate for the thread/material.

## Per-Section Template
- Required printed parts (STL names).
- Required purchased parts from `hardware/bom/bom_buy.csv`.
- Assembly steps with photos and torque notes.
- Quality checks (free rotation, no cable pinch, screw length verification).

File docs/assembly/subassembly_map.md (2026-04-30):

# Subassembly Map (Onshape -> Repo STL Groups)

This map aligns Onshape assembly naming to the current STL folder structure.

## Left leg

- `hipx_subassembly <1>` -> `hardware/cad/stl/biped_platform/left_leg/hipx/`
- `hipy_subassembly <1>` -> `hardware/cad/stl/biped_platform/left_leg/hipz/`
- `thigh_subassembly <1>` -> `hardware/cad/stl/biped_platform/left_leg/thigh/`
- `shin_subassembly <1>` -> `hardware/cad/stl/biped_platform/left_leg/shin/`
- `ankle_subassembly <1>` -> `hardware/cad/stl/biped_platform/left_leg/ankle/`
- ankle transmission parts -> `hardware/cad/stl/biped_platform/left_leg/ankle_mechanism/`
- `foot_subassembly <1>` -> `hardware/cad/stl/biped_platform/left_leg/foot/`

## Right leg

Onshape often uses mirrored names (`*_sym`) and/or second instances (`<2>`).
All right-leg exports map to canonical right-leg folders:

- `hipx_subassembly_sym <1>` / `hipx_subassembly <2>` -> `hardware/cad/stl/biped_platform/right_leg/hipx/`
- `hipy_subassembly_sym <2>` / `hipy_subassembly <2>` -> `hardware/cad/stl/biped_platform/right_leg/hipz/`
- `thigh_subassembly_sym <1>` / `thigh_subassembly <2>` -> `hardware/cad/stl/biped_platform/right_leg/thigh/`
- `shin_subassembly_sym <1>` / `shin_subassembly <2>` -> `hardware/cad/stl/biped_platform/right_leg/shin/`
- `ankle_subassembly <2>` -> `hardware/cad/stl/biped_platform/right_leg/ankle/`
- ankle transmission parts -> `hardware/cad/stl/biped_platform/right_leg/ankle_mechanism/`
- `foot_subassembly <2>` -> `hardware/cad/stl/biped_platform/right_leg/foot/`

## Torso

- torso and upper-body base elements -> `hardware/cad/stl/biped_platform/torso/`

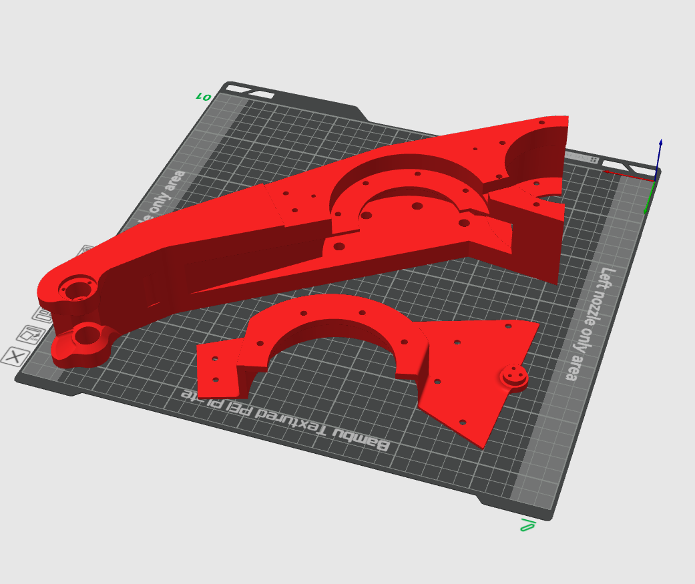
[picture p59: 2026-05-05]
docs/manufacturing/h2d_profiles/thigh_print_example.png

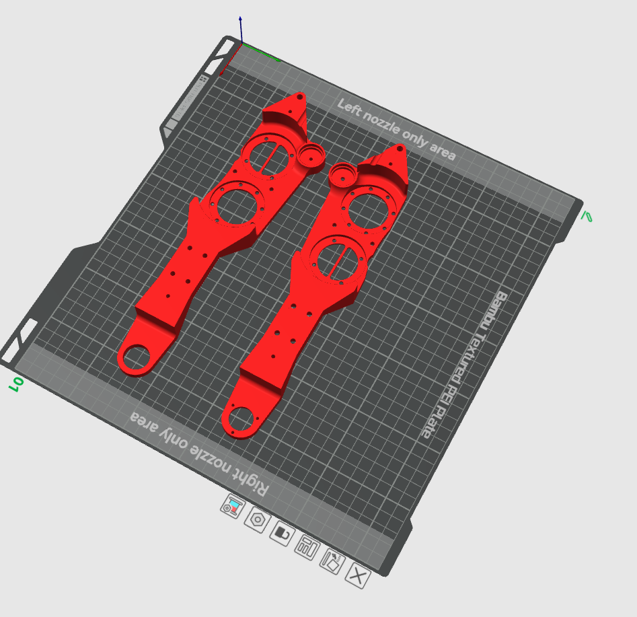
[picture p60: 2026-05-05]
docs/manufacturing/h2d_profiles/shin_tibias_print_example.png

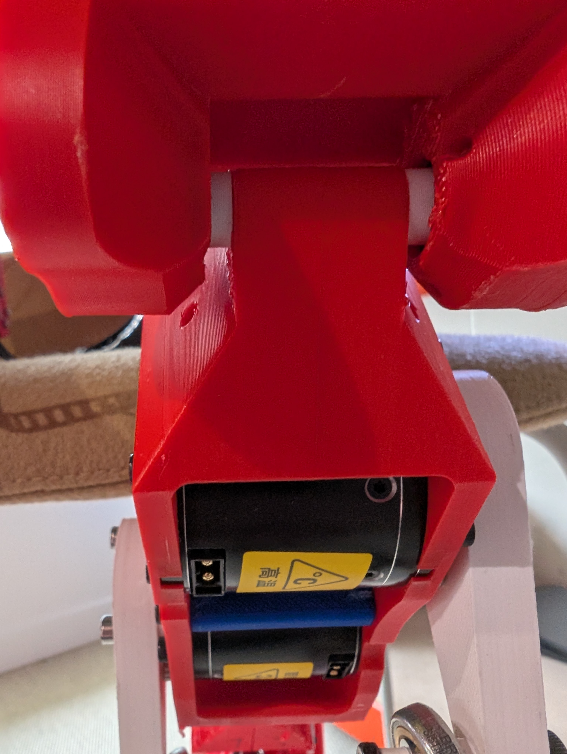
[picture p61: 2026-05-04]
docs/assembly/photos/knee_detail.jpg

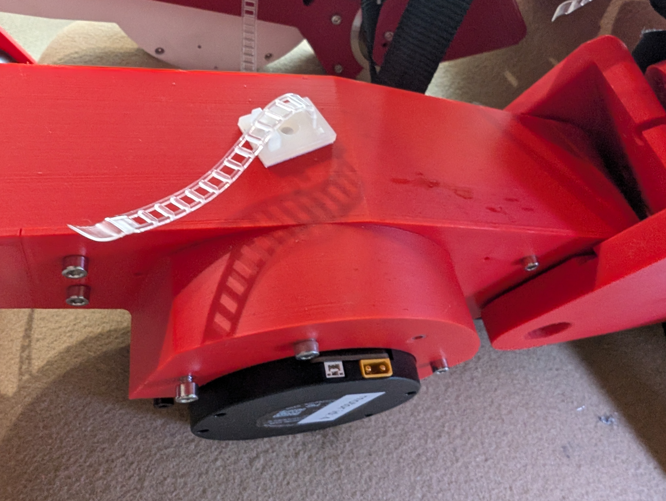
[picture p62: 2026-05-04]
docs/assembly/photos/thigh_detail.jpg

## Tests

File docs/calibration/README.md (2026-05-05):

# Runtime Boundary

Post-assembly runtime procedures are handled in:
- https://github.com/Virgileboat/lerobot-humanoid-runtime

This hardware repository covers only pre-assembly preparation:
- motor protocol/ID commissioning (`hardware/config/commission_motor.py`)

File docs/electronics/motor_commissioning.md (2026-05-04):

# Motor Commissioning

Commission every motor before mechanical assembly.

## Preconditions
- Connect only one motor on the CAN bus during commissioning.
- Adapter: `SAVVYCANFD 2CH CANFD adapter` (currently the only proven one in this project).
- Linux CAN interface is up (example: `can0`).

## Recommended Command
```bash
python hardware/config/commission_motor.py wizard --channel can0
```

Non-interactive example:
```bash
python hardware/config/commission_motor.py wizard --channel can0 --motor-model o3 --new-id 4 --yes
```

## What the Wizard Does
1. Detects motor ID and active protocol (`CANopen`, `private`, or `MIT`).
2. Switches motor to `MIT` protocol (with required reboot checkpoints).
3. Applies final motor ID according to motor model mapping.
4. Reboots and verifies final ID and protocol (`MIT`).
5. Runs motion check: set zero, enable, move to `90 deg` for `1 s`, then back to `0 deg`, then disable motor.

## Final ID Map

- `RobStride O0`: IDs `1`, `7`
- `RobStride O2`: IDs `2`, `8`
- `RobStride O3`: IDs `3`, `4`, `9`, `10`
- `RobStride O5`: IDs `5`, `6`, `11`, `12`

Use one motor at a time and assign one of the allowed IDs for its model.

## Batch Policy for This Robot
- Repeat the same process for each motor individually.
- Keep a log table: `serial`, `final_id`, `final_protocol`, `commissioning_date`.

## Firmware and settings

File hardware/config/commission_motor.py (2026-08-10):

#!/usr/bin/env python3
from __future__ import annotations

"""Commission one RobStride motor before assembly.

This utility is self-contained (no robstride_toolkit import).

Wizard flow:
1) Detect current motor ID and protocol.
2) Switch motor to MIT protocol (with reboot checkpoints).
3) Set target ID (based on motor model map).
4) Reboot and verify final ID/protocol.
5) Motion check: gentle sway between -180 and 180 deg at 0.1Hz, return to 0.
"""

import argparse
import math
import sys
import time
from enum import IntEnum
from typing import Any, Optional

try:
    import can  # type: ignore
except Exception as exc:  # pragma: no cover - runtime dependency
    can = None
    _CAN_IMPORT_ERROR = exc
else:
    _CAN_IMPORT_ERROR = None

PROTOCOLS = ("canopen", "private", "mit")
DEFAULT_PROTOCOL_ORDER = ("canopen", "private", "mit")

CAN_CMD_CLEAR_FAULT = 0xFB
CAN_CMD_ENABLE = 0xFC
CAN_CMD_DISABLE = 0xFD
CAN_CMD_SET_ZERO = 0xFE

MOTOR_MODEL_ID_MAP: dict[str, tuple[int, ...]] = {
    "o0": (1, 7),
    "o2": (2, 8),
    "o3": (3, 4, 9, 10),
    "o5": (5, 6, 11, 12),
}


class CommMode(IntEnum):
    PRIVATE = 0
    CANOPEN = 1
    MIT = 2


def _require_can() -> None:
    if can is None:
        raise RuntimeError(
            "python-can is required for motor commissioning. "
            "Install it with: pip install python-can"
        ) from _CAN_IMPORT_ERROR


def _open_bus(interface: str, channel: str):
    _require_can()
    # Explicitly set 1Mbps for RobStride defaults
    return can.interface.Bus(interface=interface, channel=channel, bitrate=1000000)


def _shutdown_bus(bus: Any) -> None:
    try:
        bus.shutdown()
    except Exception:
        pass


def _flush_bus(bus: Any, max_msgs: int = 1000) -> int:
    count = 0
    while count < max_msgs:
        msg = bus.recv(0.0005)
        if msg is None:
            break
        count += 1
    return count


def make_ext_id(comm_type: int, host_id: int, target_id: int) -> int:
    return ((comm_type & 0x1F) << 24) | ((host_id & 0xFF) << 8) | (target_id & 0xFF)


def parse_reply_id(arbitration_id: int) -> tuple[int, int, int]:
    comm_type = (arbitration_id >> 24) & 0x1F
    host_field = (arbitration_id >> 8) & 0xFF
    target_field = arbitration_id & 0xFF
    return comm_type, host_field, target_field

def ping_private(bus: Any, motor_id: int) -> bool:
    arb_id = make_ext_id(0x00, 0xFD, motor_id)
    bus.send(can.Message(arbitration_id=arb_id, data=[0]*8, is_extended_id=True))
    deadline = time.monotonic() + 0.05
    while time.monotonic() < deadline:
        msg = bus.recv(timeout=0.01)
        if msg and msg.is_extended_id: return True
    return False


def ping_mit(bus: Any, motor_id: int) -> bool:
    bus.send(can.Message(arbitration_id=motor_id, data=[0xFF]*7 + [CAN_CMD_CLEAR_FAULT], is_extended_id=False))
    deadline = time.monotonic() + 0.05
    while time.monotonic() < deadline:
        msg = bus.recv(timeout=0.01)
        if msg and not msg.is_extended_id: return True
    return False


def ping_canopen(bus: Any, motor_id: int) -> bool:
    req_id = 0x600 + motor_id
    data = [0x40, 0x00, 0x10, 0x00, 0, 0, 0, 0]
    bus.send(can.Message(arbitration_id=req_id, data=data, is_extended_id=False))
    deadline = time.monotonic() + 0.05
    while time.monotonic() < deadline:
        msg = bus.recv(timeout=0.01)
        if msg and not msg.is_extended_id and msg.arbitration_id == (0x580 + motor_id): return True
    return False


def detect_motor(bus: Any, start_id: int, end_id: int, timeout_s: float = 1.0) -> tuple[Optional[int], Optional[str]]:
    """Exact detection logic from working script, integrated with range arguments."""
    deadline = time.monotonic() + timeout_s
    # 1. Passive
    while time.monotonic() < deadline:
        msg = bus.recv(timeout=0.1)
        if msg:
            if not msg.is_extended_id:
                mid = msg.arbitration_id
                if start_id <= mid <= end_id: return mid, "mit"
            elif msg.is_extended_id and (msg.arbitration_id & 0xFFFF00) == 0:
                target = msg.arbitration_id & 0xFF
                mid = (0 if target == 0 else target)
                if mid == 0xFE: mid = 127
                if start_id <= mid <= end_id: return mid, "private"

    # 2. Active Range Scan (Fast 50ms pings)
    for mid in range(start_id, end_id + 1):
        if ping_private(bus, mid): return mid, "private"
        if ping_mit(bus, mid): return mid, "mit"
        if ping_canopen(bus, mid): return mid, "canopen"
    return None, None


def switch_private_to_mit(bus: Any, motor_id: int) -> bool:
    print(f"Sending MIT protocol switch to ID {motor_id}...")
    arb_id = make_ext_id(0x19, 0xFD, motor_id)
    data = [0x01, 0x02, 0x03, 0x04, 0x05, 0x06, 2, 0x00]
    bus.send(can.Message(arbitration_id=arb_id, data=data, is_extended_id=True))
    time.sleep(0.1)
    bus.send(can.Message(arbitration_id=make_ext_id(0x07, 0xFD, motor_id), data=[0]*8, is_extended_id=True))
    time.sleep(0.2)
    return True


def change_motor_id(bus: Any, old_id: int, new_id: int) -> bool:
    print(f"Changing MIT ID {old_id} -> {new_id}...")
    bus.send(can.Message(arbitration_id=old_id, data=[0xFF]*6 + [new_id & 0xFF, 0xFA], is_extended_id=False))
    time.sleep(0.2)
    # Flash Registration Sequence
    bus.send(can.Message(arbitration_id=new_id, data=[0x70, 0x05, 0, 0, 0, 0, 0, new_id & 0xFF], is_extended_id=False))
    time.sleep(0.1)
    bus.send(can.Message(arbitration_id=new_id, data=[0x70, 0xFF, 0, 0, 0, 0, 0, 0], is_extended_id=False))
    time.sleep(0.2)
    return True


# --- Motion Test ---

def _float_to_uint(x: float, x_min: float, x_max: float, bits: int) -> int:
    x_clamped = max(float(x_min), min(float(x_max), float(x)))
    span = float(x_max - x_min)
    return int(((x_clamped - x_min) / span) * ((1 << bits) - 1))


def mit_position_command(bus: Any, motor_id: int, pos_deg: float, kp: float = 5.0, kd: float = 0.15):
    p_rad = math.radians(pos_deg)
    q = _float_to_uint(p_rad, -12.57, 12.57, 16)
    kp_uint = _float_to_uint(kp, 0.0, 500.0, 12)
    kd_uint = _float_to_uint(kd, 0.0, 5.0, 12)
    v_uint = 2048  # Center
    t_uint = 2048  # Center

    data = [0] * 8
    data[0] = (q >> 8) & 0xFF
    data[1] = q & 0xFF
    data[2] = (v_uint >> 4) & 0xFF
    data[3] = ((v_uint & 0x0F) << 4) | ((kp_uint >> 8) & 0x0F)
    data[4] = kp_uint & 0xFF
    data[5] = (kd_uint >> 4) & 0xFF
    data[6] = ((kd_uint & 0x0F) << 4) | ((t_uint >> 8) & 0x0F)
    data[7] = t_uint & 0xFF
    bus.send(can.Message(arbitration_id=motor_id, data=data, is_extended_id=False))


def _run_motion_test(bus: Any, motor_id: int, duration_s: float):
    print(f"Starting gentle sway test (-180 to 180) on ID {motor_id}...")
    bus.send(can.Message(arbitration_id=motor_id, data=[0xFF]*7 + [CAN_CMD_ENABLE], is_extended_id=False))
    time.sleep(0.2)
    
    start_time = time.monotonic()
    frequency = 0.1  # 0.1 Hz
    try:
        while (time.monotonic() - start_time) < duration_s:
            elapsed = time.monotonic() - start_time
            target = 180.0 * math.sin(2 * math.pi * frequency * elapsed)
            mit_position_command(bus, motor_id, target)
            time.sleep(0.02)
        
        print("Returning to 0.0 degrees...")
        ret_start = time.monotonic()
        while (time.monotonic() - ret_start) < 2.0:
            mit_position_command(bus, motor_id, 0.0)
            time.sleep(0.02)
    except KeyboardInterrupt: pass
    finally:
        bus.send(can.Message(arbitration_id=motor_id, data=[0xFF]*7 + [CAN_CMD_DISABLE], is_extended_id=False))
    print("Motion test complete. Motor disabled.")


# --- Wizard and CLI ---

def _wait_reboot(*, assume_yes: bool = False) -> None:
    if assume_yes:
        time.sleep(3.0)
        return
    input(">>> Reboot motor now (Power Cycle), then press Enter to continue...")


def _cmd_scan(args):
    bus = _open_bus(args.interface, args.channel)
    try:
        print(f"Scanning IDs {args.start_id}-{args.end_id}...")
        for mid in range(args.start_id, args.end_id + 1):
            if ping_mit(bus, mid): print(f"  ID {mid:>3}: mit")
            if ping_private(bus, mid): print(f"  ID {mid:>3}: private")
            if ping_canopen(bus, mid): print(f"  ID {mid:>3}: canopen")
        return 0
    finally:
        _shutdown_bus(bus)


def _cmd_wizard(args: argparse.Namespace) -> int:
    bus = _open_bus(args.interface, args.channel)
    try:
        _flush_bus(bus)
        print("Scanning for motor...")
        motor_id, protocol = detect_motor(bus, args.start_id, args.end_id)

        if motor_id is None:
            print("No motor detected. Check wiring and power."); return 1
        print(f"Detected motor id={motor_id}, protocol={protocol}")

        # 1. Ensure MIT Protocol
        if protocol != "mit":
            if protocol == "private":
                switch_private_to_mit(bus, motor_id)
            elif protocol == "canopen":
                bus.send(can.Message(arbitration_id=make_ext_id(0x19, 0xFD, motor_id), data=[0]*8, is_extended_id=True))
            
            _wait_reboot(assume_yes=args.yes)
            _flush_bus(bus)
            # RE-DETECT: Find where the motor ended up after protocol switch (likely ID 0)
            motor_id, protocol = detect_motor(bus, 0, 127, timeout_s=3.0)
            if protocol != "mit":
                print(f"Verification failed. Found {protocol}."); return 1

        # 2. Change ID
        if motor_id != args.new_id:
            change_motor_id(bus, motor_id, args.new_id)
            _wait_reboot(assume_yes=args.yes)
            _flush_bus(bus)
            # RE-DETECT: Verify motor is at the NEW ID
            motor_id, protocol = detect_motor(bus, args.start_id, args.end_id, timeout_s=3.0)
            if motor_id != args.new_id:
                print(f"Verification failed. Motor at ID {motor_id}."); return 1

        print(f"Commissioning complete. Motor is ID {motor_id} in MIT mode.")
        if not args.skip_motion_test:
            duration = max(args.motion_duration_s, 10.0)
            _run_motion_test(bus, motor_id, duration)
        return 0
    finally:
        _shutdown_bus(bus)


def main() -> int:
    parser = argparse.ArgumentParser(description="RobStride Commissioning Utility")
    sub = parser.add_subparsers(dest="cmd", required=True)

    p_scan = sub.add_parser("scan")
    p_scan.add_argument("--interface", default="socketcan")
    p_scan.add_argument("--channel", default="can0")
    p_scan.add_argument("--start-id", type=int, default=0)
    p_scan.add_argument("--end-id", type=int, default=127)

    p_wizard = sub.add_parser("wizard")
    p_wizard.add_argument("--interface", default="socketcan")
    p_wizard.add_argument("--channel", default="can0")
    p_wizard.add_argument("--new-id", type=int, required=True)
    p_wizard.add_argument("--motor-model", choices=("o0", "o2", "o3", "o5"), required=True)
    p_wizard.add_argument("--start-id", type=int, default=0)
    p_wizard.add_argument("--end-id", type=int, default=127)
    p_wizard.add_argument("--skip-motion-test", action="store_true")
    p_wizard.add_argument("--motion-duration-s", type=float, default=10.0)
    p_wizard.add_argument("--yes", action="store_true")

    args = parser.parse_args()
    try:
        if args.cmd == "scan": return _cmd_scan(args)
        if args.cmd == "wizard": return _cmd_wizard(args)
    except KeyboardInterrupt: return 130
    except Exception as e: print(f"Error: {e}"); return 1
    return 0


if __name__ == "__main__":
    sys.exit(main())

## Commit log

2026-04-29 Add biped platform STL inventory and normalized naming
    [bearing_spacer14_5_7_3.stl, bearing_spacer24_5_7_3.stl, bearing_spacer34_5_7_3.stl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]
2026-04-30 docs: add hardware repository structure and assembly docs
    [bom.csv, bom_buy.csv]
2026-05-04 add cable
    [bom.csv, bom_buy.csv]
2026-05-04 docs: expand assembly guidance, add photos, and align BOM/runtime notes
    [bom.csv, bom_buy.csv]
2026-05-05 docs: clarify startup flow and printing baseline for builders
2026-05-05 Add H2D print profiles and support guidance
    [hip_example.3mf, shin_tibias_example.3mf, thigh_femur_example.3mf]
2026-05-05 Update runtime links and split BOM with axis/STL references
    [bom.csv, bom_buy.csv]
2026-07-18 one command to switch motor to MIT and apply proper ID
2026-07-18 can holder top file added, updated git ignore to not include ds_store files
    [bom.csv, torso_can_holder_2.stl]
2026-07-18 more in depth assembly instructions for torso
2026-07-19 marked off wwhere bearings go in torso since it was missing in instructions
2026-07-20 hipz assembly instructions
2026-07-20 image of compelted upper assembly/
2026-07-22 instructions for thighs
    [femur_v2_hat_femur_2.stl, ujoint_hat_femur_1.stl, ujoint_hat_small_1.stl]
2026-07-25 foot and ankle instructions
    [femur_hat_small_1.stl, femur_hat_small_1.stl.stl]
2026-07-25 finished first draft of assembly guide
2026-07-25 fixed file name for stl
    [femur_hat_small_1.stl]
2026-08-07 adding wiring diagram
